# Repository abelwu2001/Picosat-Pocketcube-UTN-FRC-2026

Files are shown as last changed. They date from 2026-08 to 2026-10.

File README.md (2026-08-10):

# PocketQube PoCat: análisis, ensayos y propuestas de mejora

Este repositorio reúne la documentación, los diseños electrónicos y los resultados del estudio del satélite **PocketQube PoCat**. El trabajo parte de un diseño existente y busca identificar mejoras comprobables mediante simulaciones, mediciones y comparaciones con la versión original.

> [!IMPORTANT]
> Antes de modificar una placa, hay que confirmar su revisión, función, compatibilidad mecánica y relación con las demás placas del satélite. Todos los cambios deben realizarse sobre una copia del diseño original.

## Objetivos del proyecto

- Comprender el funcionamiento completo del PocketQube.
- Identificar la función y las conexiones de cada placa.
- Reunir los resultados obtenidos por los desarrolladores del diseño original.
- Detectar limitaciones reales mediante mediciones o simulaciones.
- Seleccionar una mejora técnicamente justificable.
- Comparar el comportamiento del diseño original con el modificado.
- Documentar el procedimiento y los resultados para que puedan reproducirse.

## Configuración del satélite

### Placas y elementos principales

| Carpeta o placa | Función principal | Uso en la configuración |
|---|---|---|
| `pq_obc_comms` | Computadora de a bordo y comunicación LoRa | Se utiliza |
| `pq_eps` | Gestión de energía, MPPT, batería y distribución de tensiones | Se utiliza |
| `pq_adcs` | Determinación y control de actitud | A seleccionar (hay dos para eligir) |
| `pq_ymag_board` | Magnetorquer del eje Y | Se utiliza |
| `pq_latboard` | Placas laterales con panel solar y sensores; una incorpora la antena | Se utilizan varias unidades |
| `pq_botboard` | Placa inferior, panel solar, batería, umbilical y *killswitches* | Se utiliza |
| `pq_botnotsobot` | Placa inferior deslizante o estructural del conjunto | Se utiliza |
| `pq_pl1` | Payload de cámara VGA | A seleccionar |
| `pq_pl2` | Payload de detección RFI en banda L | A seleccionar |
| `pq_topboard` | Placa superior genérica | Alternativa al payload, según la configuración |
| `pq_egse` | Equipo eléctrico de apoyo y pruebas en tierra | No vuela |
| `assembly` | Modelos y archivos del ensamblaje mecánico | Solo documentación/diseño |

> [!WARNING]
> Puede cambiar.

## Orden funcional del sistema

El recorrido general de energía, control y datos puede resumirse así:

1. Los paneles solares entregan energía a la `pq_eps`.
2. La EPS administra la carga de la batería y alimenta las demás placas.
3. La `pq_obc_comms` controla el satélite y transmite o recibe información.
4. La `pq_adcs` mide y controla la orientación mediante sensores y magnetorquers.
5. La `pq_pl2` realiza las mediciones de interferencia en banda L.

## Posibles líneas de mejora

### 1. Mejorar el sistema de energía

- Aumentar la eficiencia de los convertidores.
- Revisar el funcionamiento del MPPT.
- Reducir el rizado de las alimentaciones.
- Mejorar el diseño térmico y las pistas de potencia.
- Disminuir las emisiones de las etapas conmutadas.

### 2. Mejorar el sistema de comunicaciones

- Optimizar la adaptación de la antena a `50 Ω`.
- Revisar la pista RF y su camino de retorno.
- Reducir armónicos del transmisor.
- Mejorar el mecanismo de despliegue.
- Comparar alcance, potencia y sensibilidad.

### 3. Mejorar el control de actitud

- Calibrar magnetómetro, giróscopo y sensores solares.
- Filtrar ruido y deriva de los sensores.
- Mejorar el algoritmo de estimación y control.
- Optimizar el accionamiento de los magnetorquers.
- Evitar que las bobinas interfieran con el magnetómetro.

### 4. Reducir interferencias electromagnéticas

- Medir el piso de ruido de PL2 en forma aislada.
- Encender cada subsistema por separado para identificar la fuente de ruido.
- Revisar planos de masa y caminos de retorno.
- Agregar filtros, ferritas, desacoplos o blindaje cuando corresponda.
- Evaluar una ventana silenciosa de medición mediante firmware.
- Comparar los espectros antes y después de la modificación.

### 5. Mejorar el payload de cámara

- Aumentar resolución o calidad de imagen.
- Reducir el consumo entre capturas.
- Incorporar memoria o compresión.
- Mejorar el protocolo de transferencia.

## Links de trabajo 

> [!NOTE]
> **Links**
>
> ```text
> Note one:
> Trello: 
> Drive:
> ```

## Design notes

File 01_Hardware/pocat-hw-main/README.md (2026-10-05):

# IEEE Open PocketQube Kit – Hardware necesario

Este documento resume las placas, elementos estructurales,
componentes externos, cableado y tornillería necesarios para
el armado de la plataforma PocketQube.

> Nota:
> No se incluyen aquí payloads específicos de las variantes
> demostradoras de la Wiki. La carga útil se considera un
> subsistema independiente/custom.
>
> Las cantidades se basan principalmente en la documentación
> de montaje y hardware del IEEE Open PocketQube Kit.
> Algunas revisiones del repositorio y de la Wiki presentan
> pequeñas diferencias, por lo que siempre debe comprobarse
> la revisión final de PCB antes de comprar componentes.

Link de la wiki donde se explica todo sobre el proyecto:
 
>https://wiki.nanosatlab.space/shelves/ieee-open-pocketqube-kit-mFR

Link BOM final

>https://docs.google.com/spreadsheets/d/18evn2hEh3wvYzuJMzKZhzkFULgpysAK2np7i2tM_1j0/edit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

# 1. PLACAS PCB

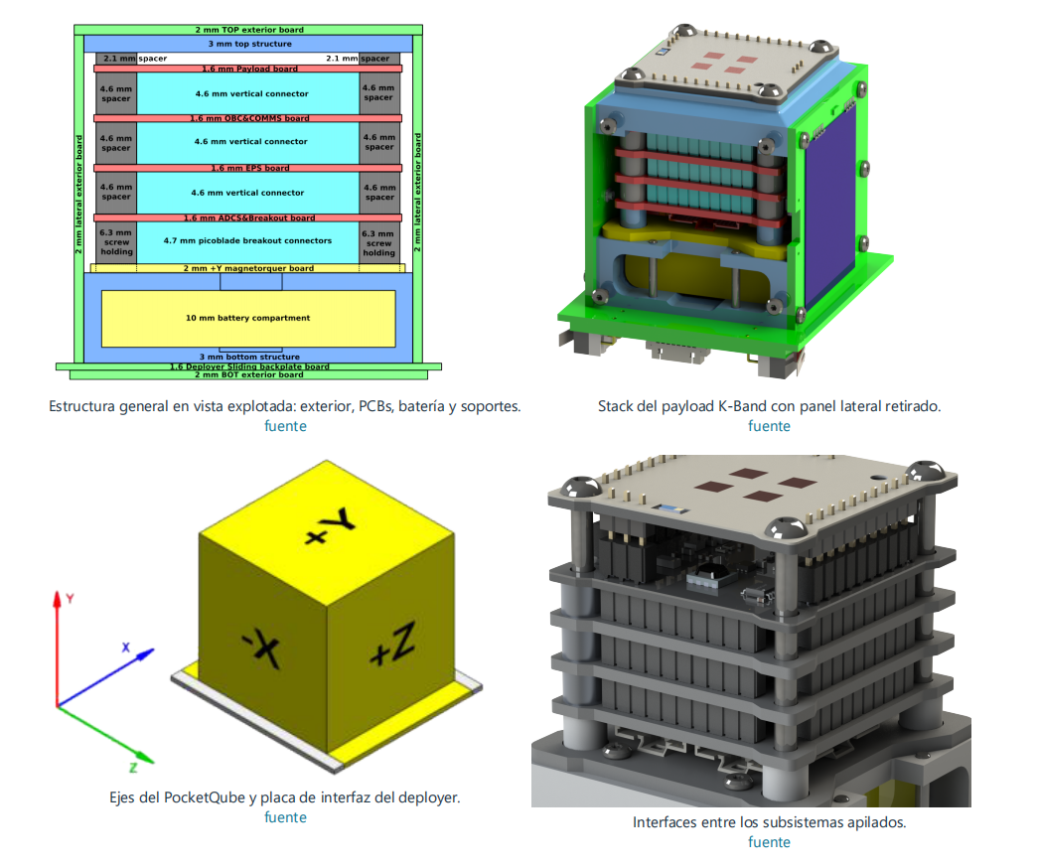
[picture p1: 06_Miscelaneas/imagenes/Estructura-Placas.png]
Estructura de Placas


## 1.1 Placas del PocketQube

| **Cantidad** | **Placa** | **Función** |
|---:|---|---|
| 1 | **PQ_ADCS_HBridge** | Control de actitud: recibe sensores y maneja los magnetorquers mediante puentes H. |
| 1 | **PQ_EPS** | Sistema de potencia: recibe energía solar, carga la batería y distribuye las tensiones del satélite. |
| 1 | **pq_obc_comms** | Computadora principal + comunicaciones por radio con tierra. |
| 1 | **pq_topboard** | Cara superior estructural e interfaz de la zona del payload. |
| 1 | **pq_botboard** | Cara inferior; integra celda solar, sensores y un magnetorquer eje -Y PCB. |
| 4 | **pq_latboard** | Caras laterales +X, -X, +Z y -Z. Integran celda solar, sensores y magnetorquer; una lleva además la antena COMMS. |
| 1 | **PQ_MagYBoard** | Magnetorquer interno dedicado al eje +Y. |
| 1 | **pq_botnotsobot** | Placa mecánica asociada al sliding/deployer y al sistema de despliegue. |
| **11** | **Total PCBs del conjunto** | Sin contar payload custom ni EGSE. |

### Magnetorquers

El PocketQube utiliza **6 magnetorquers**:

- 4 integrados en las `pq_latboard`
- 1 integrado en la `pq_botboard`
- 1 en la `PQ_MagYBoard`

Los magnetorquers integrados en las placas se forman mediante
pistas/bobinas de cobre del propio PCB, por lo que no se compran
como componentes independientes.

## 1.2 Placa de soporte en tierra

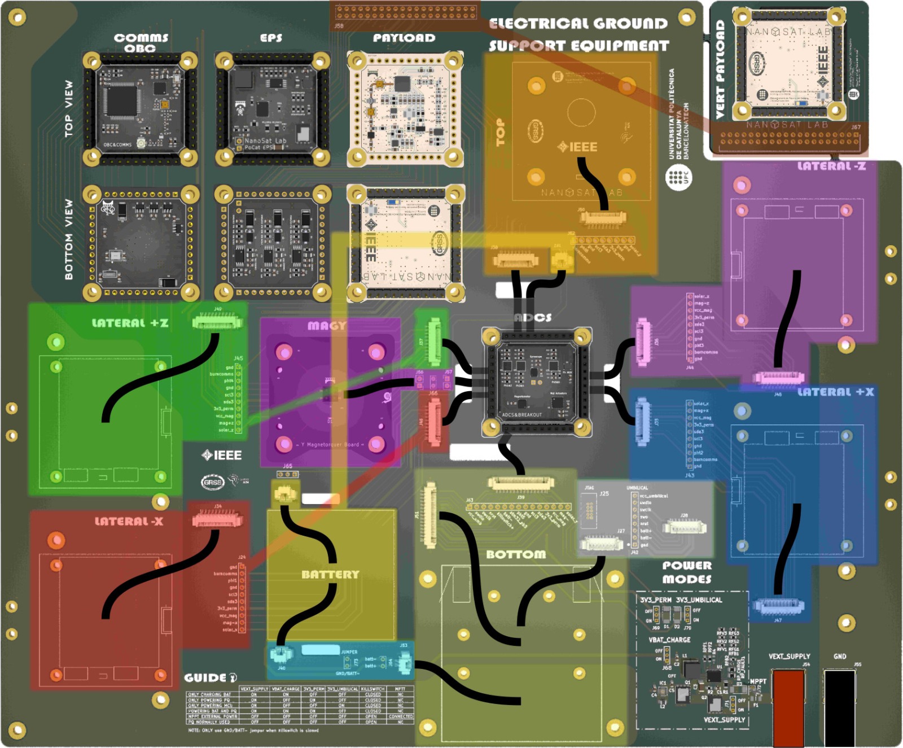
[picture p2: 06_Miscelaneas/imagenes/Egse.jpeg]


## Cableado e interconexiones

| ID | From | Num. of cables | Connector | To | Num. of cables | Connector | Length (mm) |
|---:|---|---:|---|---|---:|---|---:|
| 1 | Lat +Z | 10 | PicoBlade | PCB Connector | 10 | PicoBlade | |
| 2 | PCB Connector | 10 | PicoBlade | ADCS | 10 | PicoClasp | |
| 3 | Lat -Z | 10 | PicoBlade | PCB Connector | 10 | PicoBlade | |
| 4 | PCB Connector | 10 | PicoBlade | ADCS | 10 | PicoClasp | |
| 5 | Lat +X | 10 | PicoBlade | PCB Connector | 10 | PicoBlade | |
| 6 | PCB Connector | 10 | PicoBlade | ADCS | 10 | PicoClasp | |
| 7 | Lat -X | 10 | PicoBlade | PCB Connector | 10 | PicoBlade | |
| 8 | PCB Connector | 10 | PicoBlade | ADCS | 10 | PicoClasp | |
| 9 | Battery | 2 | PicoBlade | - | - | - | |
| 10 | PCB Connector | 2 | PicoBlade | Bottom Board | 2 | PicoBlade | |
| 11 | Battery Heater & NTC | 3 | PicoClasp | - | - | - | |
| 12 | PCB Connector | 3 | PicoClasp | ADCS | 3 | PicoClasp | |
| 13 | Umbilical | 8 | PicoBlade | PCB Connector | 8 | PicoBlade | |
| 14 | Bottom Board | 15 | PicoBlade | PCB Connector | 15 | PicoBlade | |
| 15 | PCB Connector | 15 | PicoBlade | ADCS | 15 | PicoClasp | |
| 16 | Top Board | 9 | PicoBlade | PCB Connector | 9 | PicoBlade | |
| 17 | PCB Connector | 9 | PicoBlade | ADCS | 9 | PicoClasp | |

La EGSE no forma parte del hardware de vuelo. Se utiliza en banco
para alimentación, mediciones, depuración e integración.

Por lo tanto:

- PCBs del PocketQube: 11
- PCB EGSE: 1
- Total a fabricar si se realiza todo el conjunto: 12

# 2. BATERÍA

| Cantidad | Elemento | Especificación |
|---:|---|---|
| 1 | Batería Li-ion | 3.7 V |
| 1 | Capacidad nominal | 1400 mAh |
| 1 | Energía nominal | 5.18 Wh |
| 1 | Modelo indicado en Assembly Wiki | 103540 |

La batería se instala dentro de la estructura inferior.

IMPORTANTE:
La documentación del proyecto posee revisiones que mencionan
otras baterías. Para este listado se conserva la especificación
indicada en la página de Assembly de la Wiki.

# 3. CELDAS SOLARES

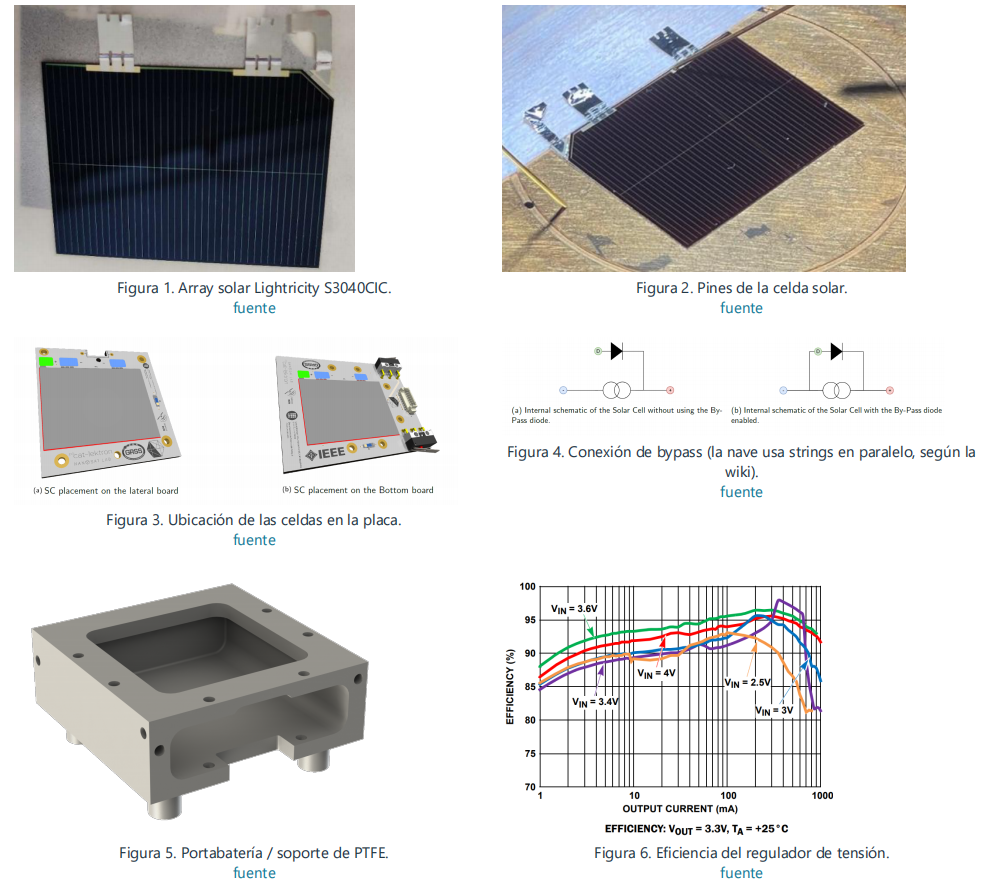
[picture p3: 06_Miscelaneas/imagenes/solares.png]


Modelo indicado:

Lightricity S3040_CIC

Características aproximadas indicadas en la Wiki:

- Tecnología: Triple Junction GaAs
- Integración: CIC
- Dimensiones: 40.15 x 30.35 x 0.30 mm
- Área fotovoltaica activa: 12 cm²
- Tensión AM0: ~2.5 V
- Potencia AM0: ~0.5 W

## Cantidad

| Ubicación | Cantidad |
|---|---:|
| Lateral +X | 1 |
| Lateral -X | 1 |
| Lateral +Z | 1 |
| Lateral -Z | 1 |
| Bottom board | 1 |
| **TOTAL** | **5** |

La plataforma utiliza:

**5 x Lightricity S3040_CIC**

La cara superior/payload no lleva celda solar en esta
configuración de la Wiki.

# 4. FOTODIODOS

Modelo indicado:

**SLCD-61N8 – Advanced Photonix**

La arquitectura ADCS utiliza un fotodiodo en cada cara para
determinar la incidencia de radiación solar.

| Ubicación | Cantidad |
|---|---:|
| Cuatro lateral boards | 4 |
| Top board | 1 |
| Bottom board | 1 |
| **TOTAL** | **6** |

Cantidad a comprar:

**6 x SLCD-61N8**

Datos principales indicados en la documentación:

- Isc aproximada: 170 µA
- Voc aproximada: 0.4 V
- Máxima sensibilidad: 930 nm
- Acceptance Half Angle: 60°

# 5. SENSORES DE TEMPERATURA

Modelo:

**TCN75A / TCN75AVOA – Microchip**

La Wiki especifica un sensor de temperatura en cada placa
lateral.

Cantidad mínima documentada para las caras laterales:

**4 x TCN75A**

Características:

- Interfaz: I2C
- Rango: -40 °C a +125 °C
- Precisión: aproximadamente ±1 °C
- Bajo consumo

Verificar en la BOM final de `topboard` y `botboard` si la
revisión fabricada incorpora sensores de temperatura
adicionales.

# 6. KILLSWITCHES

El PocketQube utiliza:

**2 x killswitches**

Los dos interruptores están conectados en serie para proporcionar
redundancia.

Su función es mantener desconectada la batería mientras el
PocketQube se encuentra dentro del deployer.

Cuando el PocketQube es liberado:

1. los killswitches dejan de estar presionados;
2. se habilita la alimentación;
3. comienza la secuencia de encendido.

IMPORTANTE:
La Wiki de Assembly los describe asociados a la estructura/PCB
inferior. El repositorio también contiene `pq_botnotsobot`,
relacionado con la interfaz de despliegue. Confirmar la ubicación
mecánica exacta con la revisión final que se vaya a fabricar.

# 7. SISTEMA DE ANTENA COMMS

Se necesita una placa lateral configurada para comunicaciones.

Elementos principales:

| Cantidad | Elemento |
|---:|---|
| 1 | Antena desplegable de cinta metálica |
| 1 | Cable RF desde OBC-COMMS |
| 1 | Dyneema / UHMWPE |
| 1 | Resorte de extensión |
| 1 | Jumper SMT de guiado |
| 2 | Resistencias thermal-knife |
| 1 | Cable clip / sujeción de antena |
| 2 | Tornillos M2.5 asociados al mecanismo |
| según diseño | Inserts/elementos de fijación |

## Dyneema

Especificación indicada:

- UHMWPE
- diámetro: 0.35 mm
- resistencia aproximada: 26 kg

La documentación de mantenimiento utiliza aproximadamente
40 cm para realizar el montaje, dejando excedente para los
nudos.

## Resorte

Modelo indicado:

**McMaster-Carr 5108N98**

Su función es mantener tensión constante sobre el Dyneema.

## Jumper SMT

Modelo indicado:

**Harwin S1731-46R**

Se utiliza como guía y para mantener el Dyneema en contacto con
los thermal knives.

## Thermal knives

La revisión actual de la página del deployer utiliza:

**2 x resistencias de baja impedancia**

Valor actualmente indicado:

**4.7 ohm**

Estas resistencias son calentadas eléctricamente mediante
`BURNCOMMS`, cortando/fundiendo el Dyneema y permitiendo que la
antena se despliegue.

IMPORTANTE:
Documentación anterior de mantenimiento menciona 7.5 ohm.
Comprobar siempre el esquemático de la revisión fabricada antes
de comprar las resistencias.

# 8. CABLEADO INTERNO

## Laterales ↔ ADCS

Cantidad:

**4 x cables planos de 10 vías PicoClasp ↔ PicoBlade**

Uno para cada lateral:

- +X
- -X
- +Z
- -Z

Cada lateral debe conectarse al conector correspondiente del
ADCS para conservar correctamente la orientación de los ejes.

## Bottom structure ↔ ADCS

Cantidad:

**1 x cable plano de 15 vías**

Conecta la estructura/PCBs inferiores con el ADCS.

## Batería

Cantidad:

**1 x cable/conector PicoBlade para batería**

La batería se conecta desde la estructura inferior.

## NTC + heater de batería

Previsto:

**1 x cable plano de 3 vías**

Conecta:

- NTC de batería
- Battery heater
- ADCS

NOTA:
La propia Wiki indica que este sistema todavía no estaba
implementado en la versión del assembly documentada.

Debe considerarse:

**OPCIONAL / A VERIFICAR SEGÚN REVISIÓN**

## Cable RF

Cantidad:

**1 x cable RF/coaxial**

Ruta:

OBC-COMMS
↓
Lateral Board COMMS
↓
Antena

# 9. CONECTOR UMBILICAL

La Bottom Board incluye una interfaz umbilical.

Se utiliza para:

- carga de batería;
- alimentación externa;
- debugging;
- NRST;
- SWCLK;
- SWDIO;
- tensión de referencia/alimentación.

Debe contemplarse:

- conector umbilical en PCB;
- conector complementario;
- cable correspondiente para banco/EGSE.

# 10. ESTRUCTURA MECÁNICA

## Estructuras principales

| Cantidad | Elemento |
|---:|---|
| 1 | Top Structure |
| 1 | Bottom Structure |
| 1 | Sliding Plate |

### Top Structure

Espesor indicado en Assembly:

**3 mm**

### Bottom Structure

La Wiki la describe mediante una configuración estructural de:

**3 mm + 10 mm + 3 mm**

### Sliding Plate

Dimensiones de referencia del estándar 1P:

- ancho: 58.0 ± 0.1 mm
- largo: 64.0 ± 0.1 mm
- espesor de referencia: 1.6 mm

# 11. TORNILLERÍA

## Tornillos

| Cantidad | Tipo |
|---:|---|
| 4 | M2 x 6 ISO 14580 |
| 2 | M2 x 20 ISO 14580 |
| 20 | M2 x 5 ISO 14850 |

## Tornillos principales del stack

Se requieren además:

**4 x tornillos/standoffs M3**

La longitud debe definirse según la altura final del stack y
de la carga útil custom.

NO se fija aquí M3x30 o M3x35 porque esos valores corresponden
a configuraciones concretas de payload documentadas en la Wiki.

# 12. SPACERS

| Cantidad | Elemento |
|---:|---|
| 4 | M2 x 5 mm Nylon |
| 4 | M3 x 2 mm Aluminium |
| 12 | M3 x 4 mm Aluminium |
| 12 | M3 x 0.5 mm Aluminium |
| según necesidad | M3 x 0.1–0.5 mm Aluminium |

La Wiki indica agregar los spacers finos necesarios para obtener
aproximadamente:

**4.6 mm de separación entre PCBs**

# 13. HELICOILS / INSERTOS ROSCADOS

| Cantidad | Tipo |
|---:|---|
| 4 | HELICOIL PLUS FREE RUNNING M3 x 2D INOX |
| 16 | HELICOIL PLUS FREE RUNNING M2 x 1.5D INOX |
| 10 | HELICOIL PLUS FREE RUNNING M2 x 1D INOX |

Uso general:

- M3: tornillos principales/standoffs;
- M2 x 1.5D: fijación de laterales;
- M2 x 1D: Bottom Board / Bottom Structure.

# 14. ARANDELAS

Cantidad:

**12 x arandelas 3.2 x 6 x 0.5 mm INOX A2 DIN 433**

También cumplen función de ajuste fino de separación mecánica.

# 15. MAGNETORQUERS

La plataforma utiliza magnetorquers PCB.

No es necesario comprar bobinas externas para los siguientes:

- +X
- -X
- +Z
- -Z
- -Y

Estos están integrados en las placas exteriores mediante pistas
de cobre.

Para el eje restante se utiliza:

**1 x PQ_MagYBoard**

correspondiente al magnetorquer interno del eje +Y.

# 16. ELEMENTOS DE LA BATERÍA

Además de la batería se contempla:

| Cantidad | Elemento | Estado |
|---:|---|---|
| 1 | NTC de batería | previsto |
| 1 | Battery heater | previsto |
| 1 | Cable 3 vías | previsto |

La Wiki indica que el NTC/heater estaba previsto pero no
implementado todavía en el assembly documentado.

Por lo tanto debe verificarse antes de realizar la compra.

# 17. CONSUMIBLES DE MONTAJE

Conviene disponer de:

- Kapton tape
- Aluminum tape
- Soldadura
- Flux
- Material de limpieza de PCB
- Elementos de crimpado
- Terminales PicoBlade
- Terminales PicoClasp
- Cableado de repuesto
- Tornillos y spacers adicionales

# 18. TORQUES DE REFERENCIA

La Wiki proporciona como referencia:

| Tornillo | Torque |
|---|---:|
| M2 | 0.2 Nm |
| M2.5 | 0.5 Nm |
| M3 | 1 Nm |
| M4 | 2 Nm |

Para la tornillería específica del PocketQube deben respetarse
los valores y límites definidos para la estructura final.

# 19. RESUMEN DE ELEMENTOS PRINCIPALES A COMPRAR

## Hardware externo principal

| Cantidad | Elemento |
|---:|---|
| 1 | Batería Li-ion 3.7 V / 1400 mAh |
| 5 | Celdas solares Lightricity S3040_CIC |
| 6 | Fotodiodos SLCD-61N8 |
| 4 mínimo | Sensores TCN75A |
| 2 | Killswitches |
| 1 | Antena COMMS |
| 1 | Cable RF |
| 1 | Dyneema 0.35 mm |
| 1 | Resorte McMaster-Carr 5108N98 |
| 1 | Harwin S1731-46R |
| 2 | Resistencias thermal-knife |
| 4 | Cables 10 vías PicoClasp-PicoBlade |
| 1 | Cable 15 vías |
| 1 | Cable/conector de batería |
| 1 | Cable 3 vías NTC/heater (si se implementa) |
| 1 | Conjunto de conector umbilical |

# 20. RESUMEN GENERAL

Para construir la plataforma completa se debe contemplar:

### Fabricación PCB

- 11 PCBs correspondientes al PocketQube.
- 1 PCB EGSE para soporte en tierra.
- Payload custom tratado independientemente.

### Energía

- 1 batería.
- 5 celdas solares.
- Cableado de batería.
- Interfaz umbilical.

### ADCS

- 6 fotodiodos.
- 4 sensores de temperatura laterales como mínimo.
- Magnetorquers integrados en las PCBs.
- 1 Magnetorquer PCB +Y.

### Seguridad / despliegue

- 2 killswitches.
- Antena desplegable.
- Dyneema.
- 2 thermal knives.
- Resorte.
- Jumper SMT.
- Sistema mecánico de sujeción.

### Interconexión

- 4 cables laterales de 10 vías.
- 1 cable inferior de 15 vías.
- 1 cable de batería.
- 1 cable RF.
- 1 cable NTC/heater si se implementa.

### Mecánica

- Top Structure.
- Bottom Structure.
- Sliding Plate.
- Tornillería M2/M3.
- Spacers.
- Helicoils.
- Arandelas.
- Kapton y materiales auxiliares.

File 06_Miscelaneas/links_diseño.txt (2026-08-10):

Diseño PCB
-----------
https://github.com/orgs/nanosatlab/repositories?utm_source=chatgpt.com

PAE Quadrimestre Tardor (QT) 2025 - On-Board Computer Software (OBC-sw) 

IEEE PocketQubes 

pocat-lektron-sw: Software developed by the IEEE GRSS Open PocketQube kit developed at the UPC NanoSat Lab. The software is also used by the PoCat-Lektron mission that is composed by PoCat-2 and PoCat-3. 

pocat-lektron-arduinoGS

tinyGS-antenna

reflow-oven

------------------------------------------------------------------------------

Software
--------

https://github.com/nanosatlab/pocat-lektron-sw?utm_source=chatgpt.com

------------------------------------------------------------------------------

Usan el STM32L476RGTX

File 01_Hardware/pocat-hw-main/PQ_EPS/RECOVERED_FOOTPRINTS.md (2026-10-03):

# Huellas recuperadas del PCB

Recovered_Project.pretty contiene una copia editable por instancia de las huellas embebidas en este PCB, exportada con KiCad. Los nombres incluyen referencia y UUID abreviado para conservar variantes y modificaciones locales. recovered-footprints.json registra el identificador original, el nuevo y los hashes.

Esta biblioteca es una instantánea del diseño existente; no representa validación del fabricante ni del repositorio NSL. Conserva también cualquier defecto pendiente de pads, courtyards o geometría. Las reglas DRC permanecen activas y los cambios futuros respecto de esta instantánea vuelven a producir avisos de discrepancia.

La operación cambia únicamente los identificadores de biblioteca del PCB y la propiedad Footprint de los símbolos colocados correspondientes. Se verifica que la serialización nativa del PCB sea idéntica salvo esos identificadores; no se sustituyen pads ni se modifican redes. Los modelos 3D conservan sus rutas originales y pueden requerir dependencias externas.

Para comparar con la fuente histórica, consultar original_fpid y sources/nanosatlab. No ejecutar Actualizar huellas desde bibliotecas de forma masiva con las bibliotecas actuales ajenas a esta instantánea sin revisar diferencias.

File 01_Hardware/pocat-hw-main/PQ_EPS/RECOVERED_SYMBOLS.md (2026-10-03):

# Símbolos recuperados del esquemático

Recovered_Symbols contiene las definiciones embebidas del proyecto. sym-lib-table conserva sus nicknames originales y apunta a estas copias locales. El esquemático y sus lib_id, pines, tipos eléctricos, cables, redes y reglas ERC permanecen intactos.

Son instantáneas del diseño histórico, no bibliotecas validadas por el fabricante. Los defectos y las variantes locales se conservan. recovered-symbols.json registra los bloques de origen mediante hashes y cualquier traducción estructural de nombre. Embedded_Local_Variants conserva exactamente los símbolos locales lib_name; si falta una definición canónica, se deriva de una de esas variantes renombrando únicamente los nombres estructurales de símbolo.

No se añadieron PWR_FLAG, exclusiones ni cambios de severidad para eliminar errores eléctricos. Los avisos de diferencia reales entre variantes locales y su definición canónica deben revisarse expresamente.

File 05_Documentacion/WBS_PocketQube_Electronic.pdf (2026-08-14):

## UNIVERSIDAD TECNOLÓGICA NACIONAL

## Facultad Regional Córdoba

# PocketQube UTN-FRC 2026

# Estructura de Desglose del Trabajo

# Work Breakdown Structure (WBS)

## Baseline: Payload PL2 - Radiómetro de banda L

Código: | PKQ-WBS-001
Revisión: | A
Estado: | Propuesta
Fecha: | 12 de agosto de 2026

PocketQube UTN-FRC 2026 | PKQ-WBS-001 | Rev. A

## Control del documento

Código | PKQ-WBS-001 | Revisión | A
Título | WBS general del proyecto PocketQube | Estado | Propuesta
Configuración | PocketQube con payload PL2 de banda
| L
Propósito | Definir el 100% del trabajo necesario
| para revisar, integrar, verificar y mejo-
| rar el diseño, con especial profundidad
| en EMC y PL2.

## Criterio de uso

Esta WBS está orientada a entregables. Las filas de nivel 3 son paquetes de trabajo controlables: cada una posee responsable, dependencia, entregable y criterio de cierre. Las fechas y los nombres personales deben completarse en la planilla editable una vez aprobados el cronograma y la matriz RACI.

- La configuración base incorpora PL2. PL1 y la topboard no se suman simultáneamente a la baseline de vuelo.
- La baseline física considera 11 placas; el EGSE integral es equipo de laboratorio, permite estimular, medir y probar el PocketQube completo en tierra, y no vuela.
- El cierre de un paquete requiere evidencia verificable, no solamente la ejecución de la actividad.
- Los cambios de alcance deben registrarse en configuración y reflejarse en requisitos, WBS y matriz V&V.

## Vista jerárquica de nivel 1

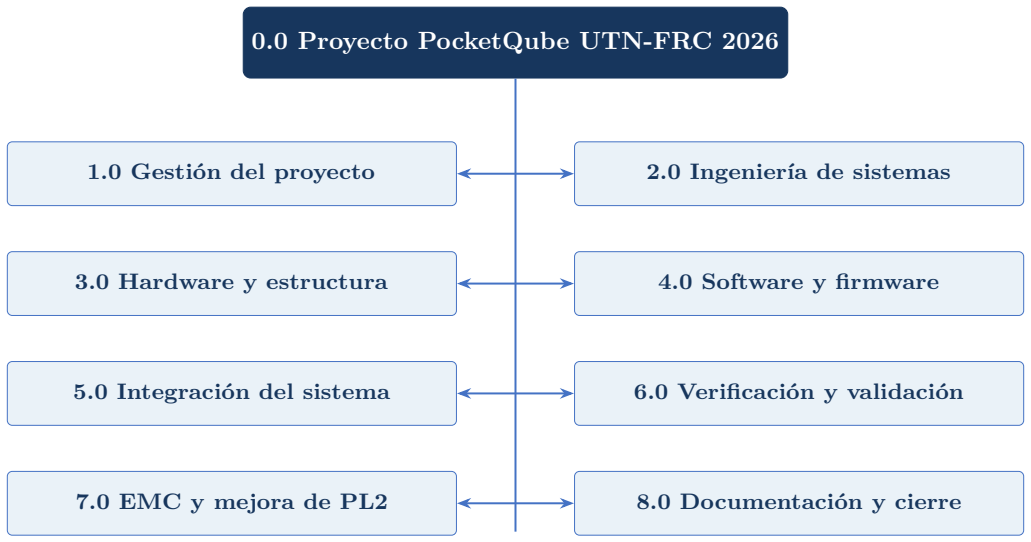
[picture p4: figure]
0.0 Proyecto PocketQube UTN-FRC 2026; 1.0 Gestión del proyecto; 2.0 Ingeniería de sistemas; 3.0 Hardware y estructura; 4.0 Software y firmware; 5.0 Integración del sistema; 6.0 Verificación y validación

7.0 EMC y mejora de PL2 | 8.0 Documentación y cierre

PocketQube UTN-FRC 2026 | PKQ-WBS-001 | Rev. A

## Resumen de fases

WBS

Fase | Propósito | Responsable funcional

1.0

Gestión del proyecto | Organizar alcance, recursos, configuración, riesgos y seguimiento del proyecto. | Líder de proyecto

2.0

Ingeniería de sistemas Convertir la necesidad de misión en requisitos, arquitectura, interfaces y presupuestos verificables.
Ingeniería de
sistemas

3.0

Hardware y estructura Revisar, caracterizar, fabricar e integrar el hardware de vuelo y sus elementos estructurales.

Equipo de hardware

4.0

Software y firmware Desarrollar el software embebido, protocolos, modos operativos y soporte de prueba.

Firmware

5.0

Integración del sistema Poner en marcha cada placa, integrar el stack y establecer una baseline funcional medible.

Ingeniería de
sistemas

6.0

Verificación y validación | Demostrar mediante evidencia objetiva que el sistema cumple sus requisitos y criterios de aceptación.

Ensayos/EMC

7.0

EMC y mejora de PL2 Identificar interferencias internas sobre el radiómetro PL2, aplicar una mejora y demostrar el cambio antes/después.

Ensayos/EMC

8.0

Documentación y
cierre

Consolidar revisiones, evidencias, entregables académicos y lecciones aprendidas.

Documentación

## Índice

1 1.0 Gestión del proyecto | 4
2 2.0 Ingeniería de sistemas | 5
3 3.0 Hardware y estructura | 6
4 4.0 Software y firmware | 8
5 5.0 Integración del sistema | 9
6 6.0 Verificación y validación | 11
7 7.0 EMC y mejora de PL2 | 13
8 8.0 Documentación y cierre | 14
Criterios para aprobar la línea base WBS | 15

PocketQube UTN-FRC 2026 PKQ-WBS-001 | Rev. A 1 1.0 Gestión del proyecto Organizar alcance, recursos, configuración, riesgos y seguimiento del proyecto. Responsable funcional de fase: Líder de proyecto WBS Paquete / actividad Entregable Responsable Dep. Criterio de cierre OK 1.1 Iniciación y organización 1.1.1 Definir alcance, misión y objetivo de mejora Acta de alcance Líder de proyecto — Alcance y exclusiones aprobados por el equipo □ 1.1.2 Identificar interesados y contactos técnicos Registro de interesados Líder de proyecto 1.1.1 Interesados, necesidades y canales de consulta registrados □ 1.1.3 Asignar roles y responsabilidades Matriz RACI Equipo completo 1.1.1 Cada paquete de trabajo tiene un responsable y un aprobador □ 1.2 Planificación 1.2.1 Definir cronograma, hitos y revisiones Cronograma maestro Líder de proyecto 1.1.3 Hitos PDR, CDR, TRR y cierre ubicados en el calendario □ 1.2.2 Estimar recursos, costos y proveedores Presupuesto y lista de proveedores Líder de proyecto 1.1.1 Costos y recursos críticos estimados con fuente □ 1.2.3 Planificar compras y disponibilidad de laboratorio Plan de adquisiciones Líder de proyecto 1.2.2 Ítems de largo plazo e instalaciones reservadas □ 1.3 Configuración y documentación 1.3.1 Definir DMS y estructura del repositorio Plan de gestión documental Documentación 1.1.1 Carpetas, códigos y responsables documentales definidos □ 1.3.2 Controlar versiones y líneas base Registro de versiones y baselines Documentación 1.3.1 Cada entregable liberado tiene código, revisión y estado □ 1.3.3 Gestionar cambios y decisiones técnicas Change log y decision log Ingeniería de sistemas 1.3.2 Cambios trazados con motivo, impacto y aprobación □ 1.4 Riesgos y seguimiento 1.4.1 Identificar y actualizar riesgos Matriz de riesgos Ingeniería de sistemas 1.1.1 Riesgos priorizados con mitigación, dueño y fecha de revisión □ 1.4.2 Realizar reuniones técnicas y minutas Minutas de reunión Líder de proyecto 1.1.3 Decisiones, acciones, responsables y vencimientos registrados □ 1.4.3 Emitir estado periódico del WBS Informe de avance Líder de proyecto 1.2.1 Avance, bloqueos y próximos hitos actualizados □

Página 4 de 15

PocketQube UTN-FRC 2026 PKQ-WBS-001 | Rev. A 2 2.0 Ingeniería de sistemas Convertir la necesidad de misión en requisitos, arquitectura, interfaces y presupuestos verificables. Responsable funcional de fase: Ingeniería de sistemas WBS Paquete / actividad Entregable Responsable Dep. Criterio de cierre OK 2.1 Requisitos y trazabilidad 2.1.1 Definir necesidad de misión y concepto de operación CONOPS Ingeniería de sistemas 1.1.1 Escenarios, actores, modos y productos de misión aprobados □ 2.1.2 Consolidar requisitos de sistema Especificación de requisitos Ingeniería de sistemas 2.1.1 Requisitos únicos, medibles y con fuente identificada □ 2.1.3 Asignar requisitos a subsistemas Árbol de requisitos Ingeniería de sistemas 2.1.2 Todo requisito de sistema está asignado a uno o más subsistemas □ 2.1.4 Construir matriz de trazabilidad y V&V RTM y matriz V&V Ingeniería de sistemas 2.1.3 Cada requisito tiene método, evidencia y criterio de verificación □ 2.2 Arquitectura y configuración 2.2.1 Definir arquitectura funcional Diagrama funcional Ingeniería de sistemas 2.1.2 Funciones, flujos de energía, datos y control identificados □ 2.2.2 Definir configuración física de vuelo con PL2 Árbol de producto y configuración Ingeniería de sistemas 2.2.1 Configuración de 11 placas físicas documentada; PL1 y topboard excluidos de la baseline □ 2.2.3 Definir interfaces eléctricas, mecánicas y de datos ICD de sistema Ingeniería de sistemas 2.2.2 Conectores, señales, tensiones, protocolos y tolerancias definidos □ 2.2.4 Definir modos operativos y transiciones Máquina de estados del sistema Firmware 2.1.1 Modos seguros, nominales, payload y contingencia definidos □ 2.3 Presupuestos de ingeniería 2.3.1 Elaborar presupuesto de masa y centro de gravedad Mass budget Mecánica 2.2.2 Masa, margen y centro de gravedad estimados por elemento □ 2.3.2 Elaborar presupuesto de potencia y energía Power budget Electrónica de potencia 2.2.4 Consumo y balance energético cerrados por modo con margen □ 2.3.3 Elaborar presupuesto de datos y memoria Data budget Firmware 2.2.4 Tasas, volúmenes, almacenamiento y tiempos de descarga estimados □ 2.3.4 Elaborar presupuesto de enlace Link budget RF/Comunicaciones 2.2.1 Margen de enlace calculado para escenarios nominal y desfavorable □ 2.3.5 Asignar márgenes térmicos y EMC Presupuesto térmico y EMC Ensayos/EMC 2.2.3 Límites de temperatura y compatibilidad asignados a subsistemas □

Página 5 de 15

PocketQube UTN-FRC 2026 PKQ-WBS-001 | Rev. A 3 3.0 Hardware y estructura Revisar, caracterizar, fabricar e integrar el hardware de vuelo y sus elementos estructurales. Responsable funcional de fase: Equipo de hardware WBS Paquete / actividad Entregable Responsable Dep. Criterio de cierre OK 3.1 EPS y sistema de energía 3.1.1 Revisar esquemático, PCB y BOM de la EPS Informe de revisión EPS Electrónica de potencia 2.2.3 Hallazgos clasificados y revisión de placa identificada □ 3.1.2 Verificar MPPT, batería y caminos de potencia Modelo funcional de energía Electrónica de potencia 3.1.1 Protecciones, límites y secuencias de energía verificados □ 3.1.3 Caracterizar eficiencia, ripple y temperatura Informe de caracterización EPS Electrónica de potencia 5.2.1 Curvas de eficiencia y ruido obtenidas para cargas representativas □ 3.2 OBC y comunicaciones 3.2.1 Revisar STM32, memoria e interfaces del OBC Informe de revisión OBC RF/Comunicaciones 2.2.3 Interfaces y recursos del OBC trazados contra requisitos □ 3.2.2 Revisar cadena RF del SX1262 y adaptación Informe RF y red de adaptación RF/Comunicaciones 3.2.1 Trayecto de 50 ohm, matching y pérdidas documentados □ 3.2.3 Caracterizar antena, despliegue y emisiones Informe de comunicaciones RF/Comunicaciones 5.2.2 Potencia, sensibilidad, S11, armónicos y despliegue medidos □ 3.3 ADCS y magnetorquers 3.3.1 Revisar sensores, drivers y alimentación del ADCS Informe de revisión ADCS ADCS 2.2.3 Sensores y actuadores asociados a interfaces y requisitos □ 3.3.2 Caracterizar Y-MAG y accionamiento magnético Informe de magnetorquer ADCS 5.2.3 Momento magnético, corriente, potencia y temperatura medidos □ 3.3.3 Calibrar sensores y validar control de detumbling Modelo y resultados ADCS ADCS 4.3.3 Offsets, escalas y reducción de velocidad angular cuantificados □ 3.4 Payload PL2 de banda L 3.4.1 Revisar arquitectura RF y banda de operación de PL2 Informe de revisión PL2 Ensayos/EMC 2.2.3 Cadena de 1 a 2 GHz, puntos de prueba y revisión de placa documentados □ 3.4.2 Verificar alimentación, control y adquisición de datos ICD validado de PL2 Firmware 3.4.1 Consumo, señales y protocolo comprobados en banco □ 3.4.3 Calibrar sensibilidad, ganancia y rango dinámico Curvas de calibración PL2 Ensayos/EMC 5.2.4 Curvas repetibles con incertidumbre y condiciones registradas □ 3.5 Estructura, paneles y seguridad 3.5.1 Verificar CAD del stack e interfaces mecánicas Modelo CAD integrado Mecánica 2.2.2 Sin colisiones y con separaciones, tornillería y tolerancias definidas □

Página 6 de 15

PocketQube UTN-FRC 2026 PKQ-WBS-001 | Rev. A WBS Paquete / actividad Entregable Responsable Dep. Criterio de cierre OK 3.5.2 Documentar bottom, sliding y laterales Plano de configuración exterior Mecánica 3.5.1 Bottom board, sliding plate, 3 laterales y lateral con antena identificados □ 3.5.3 Verificar batería, killswitches y despliegue de antena Informe de mecanismos de seguridad Mecánica 3.5.2 Retención, liberación y redundancia ensayadas sin daño □ 3.6 Liberación, fabricación y armado 3.6.1 Liberar archivos KiCad, CAD, Gerber y BOM Paquete de fabricación Documentación 3.1.1, 3.2.2, 3.5.1 Archivos revisados, versionados y coherentes con la baseline □ 3.6.2 Fabricar y controlar componentes Informe de recepción e inspección Mecánica 3.6.1 PCB y piezas cumplen dimensiones y revisión requerida □ 3.6.3 Ensamblar el stack de vuelo Unidad integrada Equipo completo 3.6.2 Montaje completo conforme a procedimiento y checklist □

Página 7 de 15

PocketQube UTN-FRC 2026 PKQ-WBS-001 | Rev. A 4 4.0 Software y firmware Desarrollar el software embebido, protocolos, modos operativos y soporte de prueba. Responsable funcional de fase: Firmware WBS Paquete / actividad Entregable Responsable Dep. Criterio de cierre OK 4.1 Arquitectura y configuración 4.1.1 Definir arquitectura de firmware y tareas Software design description Firmware 2.2.4 Módulos, tareas, interfaces y temporización definidos □ 4.1.2 Configurar repositorio, build y versionado Entorno reproducible Firmware 1.3.2 Compilación documentada y binario trazable a un commit □ 4.1.3 Definir telemetría, telecomandos y protocolos Especificación de comunicaciones Firmware 2.2.3 Tramas, unidades, rangos y manejo de errores definidos □ 4.2 Drivers de subsistemas 4.2.1 Implementar drivers de energía y housekeeping Drivers EPS/OBC Firmware 4.1.1 Lecturas y comandos verificados contra banco □ 4.2.2 Implementar driver SX1262 y enlace LoRa Driver de comunicaciones Firmware 3.2.1 TX/RX estable con control de errores y telemetría □ 4.2.3 Implementar sensores y actuadores ADCS Drivers ADCS Firmware 3.3.1 Sensores leídos y magnetorquers accionados de forma controlada □ 4.2.4 Implementar adquisición y control de PL2 Driver PL2 Firmware 3.4.2 Mediciones adquiridas, marcadas temporalmente y almacenadas □ 4.3 Aplicación de vuelo 4.3.1 Implementar máquina de estados y modo seguro Aplicación de vuelo Firmware 4.2.1 Transiciones nominales y de contingencia verificadas □ 4.3.2 Implementar housekeeping, alarmas y recuperación Gestión de fallas Firmware 4.3.1 Límites y acciones de recuperación probados □ 4.3.3 Implementar control ADCS y secuencias de misión Algoritmos de misión ADCS 4.2.3 Secuencias ejecutadas con temporización y saturaciones controladas □ 4.4 Verificación y liberación 4.4.1 Ejecutar pruebas unitarias y análisis estático Informe de pruebas de software Firmware 4.2 Casos críticos cubiertos y defectos severos cerrados □ 4.4.2 Ejecutar pruebas hardware-in-the-loop con EGSE Resultados HIL Firmware 5.1.4 Interfaces y escenarios de falla verificados con hardware □ 4.4.3 Liberar versión candidata de vuelo Binario y release notes Firmware 4.4.1, 4.4.2 Binario identificado, reproducible y aprobado para integración □

Página 8 de 15

PocketQube UTN-FRC 2026 PKQ-WBS-001 | Rev. A 5 5.0 Integración del sistema Poner en marcha cada placa, integrar el stack y establecer una baseline funcional medible. Responsable funcional de fase: Ingeniería de sistemas WBS Paquete / actividad Entregable Responsable Dep. Criterio de cierre OK 5.1 EGSE y banco de pruebas 5.1.1 Preparar alimentación protegida y cargas electrónicas Banco eléctrico Electrónica de potencia 2.2.3 Límites, protecciones y puntos de medición verificados □ 5.1.2 Preparar instrumentación y adquisición de datos Plan de instrumentación Ensayos/EMC 5.1.1 Instrumentos identificados, calibrados y con incertidumbre conocida □ 5.1.3 Diseñar el EGSE integral del PocketQube Arquitectura, planos y procedimientos del EGSE Equipo completo 5.1.1, 5.1.2 El EGSE permite alimentar, estimular, comandar, medir y registrar el comportamiento de EPS, OBC/COMMS, ADCS y payload como sistema completo □ 5.1.4 Construir e integrar la interfaz cableada del EGSE EGSE cableado operativo Electrónica/Ensayos 5.1.3 Alimentación, buses, comandos, telemetría y puntos de medición funcionan mediante una conexión segura y repetible □ 5.1.5 Implementar la interfaz inalámbrica del EGSE mediante las antenas del PocketQube Banco RF y enlace inalámbrico de prueba RF/Comunicaciones 5.1.3, 3.2.1 Enlace TX/RX extremo a extremo verificado usando las antenas del PocketQube, con niveles y tráfico registrados □ 5.2 Bring-up por subsistema 5.2.1 Realizar bring-up de EPS Checklist EPS Electrónica de potencia 5.1.4 Tensiones, protecciones y telemetría dentro de límites □ 5.2.2 Realizar bring-up de OBC/COMMS Checklist OBC/COMMS RF/Comunicaciones 5.1.4 Boot, interfaces y enlace básico operativos □ 5.2.3 Realizar bring-up de ADCS Checklist ADCS ADCS 5.1.4 Sensores y actuadores responden sin sobreconsumo □ 5.2.4 Realizar bring-up de PL2 Checklist PL2 Ensayos/EMC 5.1.4 Adquisición estable y piso de ruido inicial registrado □ 5.3 Integración progresiva 5.3.1 Integrar placas por etapas Stack parcialmente integrado Equipo completo 5.2 Cada incorporación conserva las funciones ya verificadas □ 5.3.2 Verificar interfaces eléctricas, de datos y mecánicas Informe de interfaces Ingeniería de sistemas 5.3.1 Sin incompatibilidades, resets ni interferencias mecánicas críticas □ 5.3.3 Ejecutar prueba funcional del stack completo Baseline funcional Equipo completo 4.4.3, 5.3.2 Modos nominales y seguros completados con registro de datos □

Página 9 de 15

PocketQube UTN-FRC 2026 PKQ-WBS-001 | Rev. A WBS Paquete / actividad Entregable Responsable Dep. Criterio de cierre OK 5.3.4 Ejecutar prueba extremo a extremo del PocketQube completo con el EGSE Informe de prueba integral cableada e inalámbrica Equipo completo 5.1.4, 5.1.5, 5.3.3 El satélite completo es operado y medido en tierra por conexión cableada y por enlace inalámbrico usando sus antenas □ 5.4 Configuración as-built 5.4.1 Registrar configuración, revisiones y números de serie Lista as-built Documentación 5.3.4 Unidad física trazable a archivos y componentes □ 5.4.2 Actualizar presupuestos con valores medidos Budgets actualizados Ingeniería de sistemas 5.3.4 Masa, potencia, datos y márgenes reconciliados □

Página 10 de 15

PocketQube UTN-FRC 2026 PKQ-WBS-001 | Rev. A 6 6.0 Verificación y validación Demostrar mediante evidencia objetiva que el sistema cumple sus requisitos y criterios de aceptación. Responsable funcional de fase: Ensayos/EMC WBS Paquete / actividad Entregable Responsable Dep. Criterio de cierre OK 6.1 Planificación de V&V 6.1.1 Definir plan maestro de verificación Plan V&V Ingeniería de sistemas 2.1.4 Todos los requisitos tienen método, nivel y responsable □ 6.1.2 Cuantificar criterios de aceptación Matriz de aceptación Ingeniería de sistemas 6.1.1 Criterios numéricos y reglas de pass/fail aprobados □ 6.1.3 Definir configuración e instrumentación de ensayo Procedimientos de ensayo Ensayos/EMC 6.1.2 Configuración, instrumentos y datos requeridos definidos □ 6.2 Pruebas funcionales y eléctricas 6.2.1 Verificar modos, comandos y recuperación Informe funcional Firmware 5.3.3 Secuencias completas sin fallas no explicadas □ 6.2.2 Verificar batería, protecciones y killswitches Informe de seguridad eléctrica Electrónica de potencia 3.5.3 Inhibición, encendido y protecciones cumplen criterios □ 6.2.3 Ejecutar ensayo de autonomía y operación prolongada Informe de endurance Equipo completo 6.2.1 Operación sostenida sin degradación ni reset no previsto □ 6.3 Pruebas RF y comunicaciones 6.3.1 Medir S11, ROE y ancho de banda de antena Informe de adaptación RF/Comunicaciones 3.2.3 Resultados comparados con límites y configuración de montaje □ 6.3.2 Medir potencia, sensibilidad y alcance Informe de enlace RF/Comunicaciones 6.3.1 Margen de enlace reconciliado con mediciones □ 6.3.3 Medir espectro y armónicos del transmisor Informe de emisiones RF Ensayos/EMC 6.3.2 Armónicos, incluido 1736 MHz, cuantificados □ 6.4 Pruebas ADCS 6.4.1 Verificar calibración y ruido de sensores Informe de sensores ADCS ADCS 3.3.3 Sesgo, ruido, deriva y desalineación cuantificados □ 6.4.2 Verificar actuación y detumbling Informe de control ADCS ADCS 6.4.1 Momento magnético y tiempo de estabilización medidos o correlacionados □ 6.5 Pruebas mecánicas y ambientales 6.5.1 Verificar masa, dimensiones y centro de gravedad Informe dimensional y de masa Mecánica 3.6.3 Unidad dentro de envolvente y presupuesto aprobados □ 6.5.2 Ejecutar vibración o correlación modal Informe de vibración Mecánica 6.5.1 Integridad y frecuencias naturales verificadas □ 6.5.3 Ejecutar ensayo térmico disponible Informe térmico Mecánica 6.5.1 Temperaturas y funcionamiento dentro de límites □

Página 11 de 15

PocketQube UTN-FRC 2026 PKQ-WBS-001 | Rev. A WBS Paquete / actividad Entregable Responsable Dep. Criterio de cierre OK 6.6 Aceptación del sistema 6.6.1 Cerrar matriz de trazabilidad RTM con evidencias Ingeniería de sistemas 6.2, 6.3, 6.4, 6.5 Requisitos verificados o desviaciones formalmente aceptadas □ 6.6.2 Cerrar anomalías y acciones correctivas Registro de anomalías cerrado Equipo completo 6.6.1 Sin anomalías críticas abiertas □ 6.6.3 Emitir informe de aceptación Informe de aceptación Ingeniería de sistemas 6.6.2 Resultado global aprobado por el equipo □

Página 12 de 15

PocketQube UTN-FRC 2026 PKQ-WBS-001 | Rev. A 7 7.0 EMC y mejora de PL2 Identificar interferencias internas sobre el radiómetro PL2, aplicar una mejora y demostrar el cambio antes/después. Responsable funcional de fase: Ensayos/EMC WBS Paquete / actividad Entregable Responsable Dep. Criterio de cierre OK 7.1 Baseline electromagnética 7.1.1 Medir piso de ruido de PL2 aislado Espectro baseline PL2 Ensayos/EMC 3.4.3 Piso de ruido repetible con incertidumbre registrada □ 7.1.2 Definir matriz de modos encendido/apagado Matriz de ensayos EMC Ensayos/EMC 5.3.3 Combinaciones EPS, LoRa, ADCS y PL2 cubiertas □ 7.1.3 Medir emisiones conducidas y radiadas Dataset EMC baseline Ensayos/EMC 7.1.1, 7.1.2 Espectros y condiciones sincronizados por modo □ 7.2 Identificación de fuentes 7.2.1 Caracterizar ruido de EPS y MPPT Mapa de interferencia EPS Electrónica de potencia 7.1.3 Picos asociados a conversores identificados y cuantificados □ 7.2.2 Caracterizar LoRa y armónico de 1736 MHz Mapa de interferencia COMMS RF/Comunicaciones 7.1.3 Acoplamiento del fundamental y armónicos sobre PL2 cuantificado □ 7.2.3 Caracterizar relojes, buses y actividad digital Mapa de interferencia digital Firmware 7.1.3 Líneas espectrales correlacionadas con señales digitales □ 7.2.4 Caracterizar ADCS y magnetorquers Mapa de interferencia ADCS ADCS 7.1.3 Transitorios y acoplamientos durante actuación cuantificados □ 7.3 Diseño de mitigaciones 7.3.1 Diseñar filtrado de alimentación y retornos Propuesta de filtro y GND Electrónica de potencia 7.2.1 Pérdidas, estabilidad y atenuación estimadas □ 7.3.2 Diseñar mitigación RF, layout o blindaje Propuesta RF/PCB RF/Comunicaciones 7.2.2 Atenuación prevista sin degradar el enlace □ 7.3.3 Implementar ventana silenciosa por firmware Secuencia quiet mode Firmware 7.2.3, 7.2.4 PL2 mide con emisores seleccionados temporalmente inactivos □ 7.3.4 Seleccionar e implementar la mejora Prototipo modificado Equipo completo 7.3.1, 7.3.2, 7.3.3 Cambio elegido mediante evidencia, riesgo y costo □ 7.4 Verificación de la mejora 7.4.1 Repetir ensayos antes/después Dataset comparativo Ensayos/EMC 7.3.4 Mismas condiciones y configuración documentadas □ 7.4.2 Cuantificar mejora e incertidumbre Análisis estadístico EMC Ensayos/EMC 7.4.1 Reducción de ruido y efecto sobre desempeño expresados numéricamente □ 7.4.3 Actualizar diseño, requisitos e informe EMC Informe técnico de mejora Ingeniería de sistemas 7.4.2 Resultados trazados a cambios y criterios de aceptación □

Página 13 de 15

PocketQube UTN-FRC 2026 PKQ-WBS-001 | Rev. A 8 8.0 Documentación y cierre Consolidar revisiones, evidencias, entregables académicos y lecciones aprendidas. Responsable funcional de fase: Documentación WBS Paquete / actividad Entregable Responsable Dep. Criterio de cierre OK 8.1 Revisiones técnicas 8.1.1 Preparar y realizar PDR Paquete PDR y acta Ingeniería de sistemas 2.3 Arquitectura y plan de verificación aprobados □ 8.1.2 Preparar y realizar CDR Paquete CDR y acta Ingeniería de sistemas 3.6.1, 4.1 Diseño detallado liberado para integración □ 8.1.3 Preparar y realizar TRR Paquete TRR y acta Ensayos/EMC 6.1.3 Procedimientos, unidad e instrumentación listos □ 8.1.4 Preparar revisión final Paquete de revisión final Líder de proyecto 6.6.3, 7.4.3 Cumplimiento, desviaciones y conclusiones aprobados □ 8.2 Documentación técnica 8.2.1 Consolidar memoria de diseño y decisiones Design history file Documentación 8.1.2 Decisiones y cambios vinculados a requisitos y revisiones □ 8.2.2 Consolidar BOM, planos, esquemáticos y software Paquete de datos técnicos Documentación 5.4.1 Archivos finales coherentes con la unidad as-built □ 8.2.3 Consolidar informes y datos de ensayo Repositorio de evidencias Ensayos/EMC 6.6.3 Datos, scripts, calibraciones e informes auditables □ 8.2.4 Redactar manual de integración y operación Manual técnico Documentación 5.3.3 Procedimientos reproducibles y advertencias de seguridad incluidas □ 8.3 Entrega académica y cierre 8.3.1 Redactar informe de avance Informe de avance Equipo completo 1.4.3 Estado, resultados parciales y próximos pasos documentados □ 8.3.2 Redactar informe técnico final Trabajo final/PPS Equipo completo 8.2.1, 8.2.3 Objetivos, metodología, resultados y conclusiones completos □ 8.3.3 Preparar presentación y defensa Presentación final Equipo completo 8.3.2 Relato técnico ensayado y preguntas críticas preparadas □ 8.3.4 Archivar baseline y lecciones aprendidas Cierre de proyecto Líder de proyecto 8.3.3 Repositorio congelado, pendientes transferidos y lecciones registradas □

Página 14 de 15

PocketQube UTN-FRC 2026 | PKQ-WBS-001 | Rev. A

## Criterios para aprobar la línea base WBS

1. La configuración de vuelo y las exclusiones están confirmadas por los responsables del diseño original.
2. Cada paquete de nivel 3 tiene responsable nominal, duración, dependencia y evidencia esperada.
3. Los presupuestos de masa, potencia, datos y enlace poseen margen y fuente trazable.
4. La matriz V&V cubre cada requisito y referencia un procedimiento o análisis.
5. El plan EMC separa baseline, identificación de fuentes, mitigación y comparación antes/después.
6. Los hitos PDR, CDR, TRR y revisión final poseen criterios de entrada y salida.

Fin del documento - PKQ-WBS-001 Rev. A

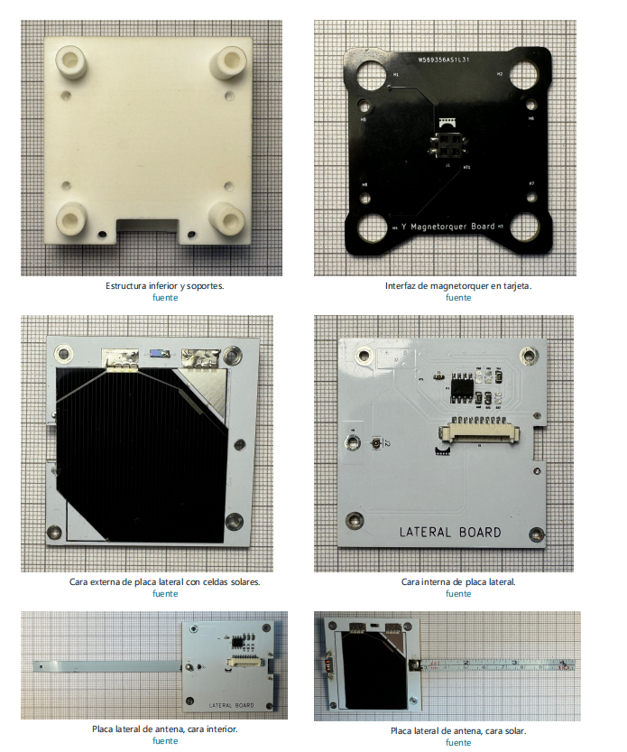
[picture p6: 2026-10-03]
06_Miscelaneas/imagenes/Placas-2.png

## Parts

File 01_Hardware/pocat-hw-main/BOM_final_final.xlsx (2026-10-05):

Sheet: EPS
PQ_EPS — BOM preparada
Datos del RAR revisado. DOCUMENTADO = MPN del proyecto. PROPUESTO / REVISAR = selección pendiente de aprobación técnica. EXCLUIR = no comprar/montar. Cantidades por placa.
Line # | Reference Designator | Qty | Value / Description | Manufacturer | Manufacturer Part Number | Package / Footprint | Type (SMD/THT) | Status | Instructions / Notes | Source
2 | C1 | 1 | 2.2u | Murata | GRM155R61C225KE11D | 0603 (1608 Metric); C_0603_1608Metric | SMD | DOCUMENTADO |  | PQ_EPS.kicad_sch + PQ_EPS.kicad_pcb https://www.murata.com/en-us/products/productdetail?partno=GRM155R61C225KE11D
3 | C2 | 1 | 10u | Murata | GRM188R61A106KAALD | 0603 (1608 Metric); C_0603_1608Metric | SMD | DOCUMENTADO | MPN documentado en el proyecto; huella recuperada del PCB. | PQ_EPS.kicad_sch + PQ_EPS.kicad_pcb https://www.mouser.com/ProductDetail/Murata-Electronics/GRM188R61A106KAALD
4 | C3 | 1 | 100u | Murata | GRM21BR60J107ME15K | 1206 (3216 Metric); C_1206_3216Metric | SMD | DOCUMENTADO |  | PQ_EPS.kicad_sch + PQ_EPS.kicad_pcb
5 | C4 | 1 | 0.1u | KEMET | C0603C104K8PACTU | 0603 (1608 Metric); C_0603_1608Metric | SMD | DOCUMENTADO | MPN documentado en el proyecto; huella recuperada del PCB. | PQ_EPS.kicad_sch + PQ_EPS.kicad_pcb https://www.digikey.com/en/products/detail/kemet/C0603C104K8PACTU/8572408
6 | C5 | 1 | 22u | Murata | GRM187R61A226ME15J | 0603 (1608 Metric); C_0603_1608Metric | SMD | DOCUMENTADO | MPN documentado en el proyecto; huella recuperada del PCB. | PQ_EPS.kicad_sch + PQ_EPS.kicad_pcb https://www.murata-electronics.com/GRM187R61A226ME15J/10095848
7 | CF1,CF2,CF3 | 3 | 1u | Murata | GRM155R61C105KA12D | 0603 (1608 Metric); C_0603_1608Metric | SMD | DOCUMENTADO |  | PQ_EPS.kicad_sch + PQ_EPS.kicad_pcb
8 | CIN1,CIN2,CIN3 | 3 | 1.5u | TDK | C1005X5R1V155K050BC | 0603 (1608 Metric); C_0603_1608Metric | SMD | DOCUMENTADO |  | PQ_EPS.kicad_sch + PQ_EPS.kicad_pcb https://product.tdk.com/en/search/capacitor/ceramic/mlcc/info?part_no=C1005X5R1V155K050BC
9 | CINSNS1 | 1 | 1n | Murata | GRM155R61A102KA01D | 0603 (1608 Metric); C_0603_1608Metric | SMD | DOCUMENTADO |  | PQ_EPS.kicad_sch + PQ_EPS.kicad_pcb + recovered-footprints.json
10 | CINSNS2 | 1 | 1n | Murata | GRM155R61A102KA01D | 0603 (1608 Metric); C_0603_1608Metric | SMD | DOCUMENTADO |  | PQ_EPS.kicad_sch + PQ_EPS.kicad_pcb + recovered-footprints.json
11 | CINSNS3 | 1 | 1n | Murata | GRM155R61A102KA01D | 0603 (1608 Metric); C_0603_1608Metric | SMD | DOCUMENTADO |  | PQ_EPS.kicad_sch + PQ_EPS.kicad_pcb + recovered-footprints.json
12 | COUT1 | 1 | 10u | Murata | GRM188R61A106KAALD | 0603 (1608 Metric); C_0603_1608Metric | SMD | DOCUMENTADO |  | PQ_EPS.kicad_sch + PQ_EPS.kicad_pcb + recovered-footprints.json https://www.mouser.com/ProductDetail/Murata-Electronics/GRM188R61A106KAALD
13 | COUT2,COUT3 | 2 | 10u | Murata | GRM188R61A106KAALD | 0603 (1608 Metric); C_0603_1608Metric | SMD | DOCUMENTADO | MPN documentado en el proyecto; huella recuperada del PCB. | PQ_EPS.kicad_sch + PQ_EPS.kicad_pcb https://www.mouser.com/ProductDetail/Murata-Electronics/GRM188R61A106KAALD
14 | COUTSNS1 | 1 | 1n | Murata | GRM155R61A102KA01D | 0603 (1608 Metric); C_0603_1608Metric | SMD | DOCUMENTADO |  | PQ_EPS.kicad_sch + PQ_EPS.kicad_pcb + recovered-footprints.json
15 | COUTSNS2 | 1 | 1n | Murata | GRM155R61A102KA01D | 0603 (1608 Metric); C_0603_1608Metric | SMD | DOCUMENTADO |  | PQ_EPS.kicad_sch + PQ_EPS.kicad_pcb + recovered-footprints.json
16 | COUTSNS3 | 1 | 1n | Murata | GRM155R61A102KA01D | 0603 (1608 Metric); C_0603_1608Metric | SMD | DOCUMENTADO |  | PQ_EPS.kicad_sch + PQ_EPS.kicad_pcb + recovered-footprints.json
17 | D1,D2,D3 | 3 | SMM4F | STMicroelectronics | SMM4F18A-TR | STmite Flat; huella SMM4F15ATR; SMM4F15ATR | SMD | DOCUMENTADO |  | PQ_EPS.kicad_sch + PQ_EPS.kicad_pcb
18 | D4,D5,D6 | 3 | shottky | ROHM Semiconductor | RBS1LAM40ATR | SOD-128 (PMDTM); RBS1LAM40ATR_Schottky | SMD | DOCUMENTADO | MPN documentado en el proyecto; huella recuperada del PCB. | PQ_EPS.kicad_sch + PQ_EPS.kicad_pcb https://www.rohm.com/products/diodes/schottky-barrier-diodes/ultra-low-vf/rbs1lam40a-product
19 | DNC1,DNC2 | 2 | 20k | Panasonic | ERJ-UP3J203V | 0603 (1608 Metric); R_0603_1608Metric | SMD | DOCUMENTADO | MPN documentado en el proyecto; huella recuperada del PCB. | PQ_EPS.kicad_sch + PQ_EPS.kicad_pcb
21 | IC1 | 1 | DS2782E+ | Analog Devices | DS2782E+ | TSSOP-8 4.4x3mm P0.65mm; TSSOP-8_4.4x3mm_P0.65mm | SMD | DOCUMENTADO | MPN documentado en el proyecto; huella recuperada del PCB. | PQ_EPS.kicad_sch + PQ_EPS.kicad_pcb https://www.analog.com/media/en/technical-documentation/data-sheets/DS2782.pdf
22 | IC2 | 1 | ISL9120IRTNZ | Renesas / Intersil | ISL9120IRTNZ | TQFN-12, 3 x 3 mm; ISL9120IRTNZ | SMD | DOCUMENTADO | MPN documentado en el proyecto; huella recuperada del PCB. | PQ_EPS.kicad_sch + PQ_EPS.kicad_pcb https://www.renesas.com/en/products/isl9120/part-details/isl9120irtnz
23 | J1,J2,J3,J4 | 4 | CES-110-02-L-S | Samtec | CES-110-02-L-S | Socket 1x10, paso 2.54 mm; SLW-110-01 | THT | DOCUMENTADO | MPN documentado en el proyecto; huella recuperada del PCB. | PQ_EPS.kicad_sch + PQ_EPS.kicad_pcb
24 | J5 | 1 | CES-102-02 | Samtec | CES-102-02-L-S | Socket 1x2, paso 2.54 mm; CES-102-02 | THT | DOCUMENTADO | Modelo propuesto según huella CES-102-02. Confirmar altura y acabado. | PQ_EPS.kicad_sch + PQ_EPS.kicad_pcb https://www.samtec.com/products/ces-102-02-l-s
25 | L1,L2,L3 | 3 | 10u | Murata | LQH2MPZ100MGRL | 0805 (2012 Metric); L_0805_2012Metric | SMD | DOCUMENTADO | Inductor de cuerpo 2.0 x 1.6 mm sobre huella L_0805: comparar land pattern del fabricante. | PQ_EPS.kicad_sch + PQ_EPS.kicad_pcb https://www.digikey.com/en/products/detail/murata-electronics/LQH2MPZ100MGRL/6799349
26 | L4 | 1 | 2.2u | Coilcraft | XAL5030-222MEC | XAL5030, huella específica 5 x 5 mm; XAL5030222MEC | SMD | DOCUMENTADO | MPN documentado en el proyecto; huella recuperada del PCB. | PQ_EPS.kicad_sch + PQ_EPS.kicad_pcb
27 | L5 | 1 | 1u | TDK | TFM201610GHM-1R0MTAA | 0805 (2012 Metric); L_0805_2012Metric | SMD | DOCUMENTADO | MPN discordantes en el proyecto: TFM201610GHM1R0A, TFM201610GHM-1R0MTAA. Inductor de cuerpo 2.0 x 1.6 mm sobre huella L_0805: comparar land pattern del fabricante. | PQ_EPS.kicad_sch + PQ_EPS.kicad_pcb https://www.digikey.com/en/products/detail/tdk/TFM201610GHM-1R0MTAA/5773536
28 | Q1 | 1 | SIR424DP | Vishay | SIR424DP-T1-GE3 | PowerPAK SO-8; SIR424DP | SMD | DOCUMENTADO | MPN documentado en el proyecto; huella recuperada del PCB. | PQ_EPS.kicad_sch + PQ_EPS.kicad_pcb https://www.vishay.com/en/product/64830/
29 | R1,R2,R3,R8 | 4 | 1k | YAGEO | RC0603FR-071KL | 0603 (1608 Metric); R_0603_1608Metric | SMD | DOCUMENTADO | Propuesta: 1%; confirmar potencia y TCR. | PQ_EPS.kicad_sch + PQ_EPS.kicad_pcb https://www.yageogroup.com/component-documentation/download/specsheet/RC0603FR-071KL
30 | R4 | 1 | 75m | KOA Speer | UR73V2ATTD75L0F | 0805 (2012 Metric); R_0805_2012Metric | SMD | DOCUMENTADO | MPN documentado en el proyecto; huella recuperada del PCB. | PQ_EPS.kicad_sch + PQ_EPS.kicad_pcb https://www.digikey.com/en/products/detail/koa-speer-electronics-inc/UR73V2ATTD75L0F/9845704
31 | R6 | 1 | 2k | YAGEO | RC0603FR-072KL | 0603 (1608 Metric); R_0603_1608Metric | SMD | DOCUMENTADO | Propuesta: 1%; confirmar potencia y TCR. | PQ_EPS.kicad_sch + PQ_EPS.kicad_pcb https://www.yageogroup.com/component-documentation/download/specsheet/RC0603FR-072KL
32 | R7 | 1 | 510 | YAGEO | RC0603FR-07510RL | 0603 (1608 Metric); R_0603_1608Metric | SMD | DOCUMENTADO | Propuesta: 1%; confirmar potencia y TCR. | PQ_EPS.kicad_sch + PQ_EPS.kicad_pcb https://www.yageogroup.com/component-documentation/download/specsheet/RC0603FR-07510RL
33 | R9 | 1 | 15m | Vishay Dale | WSL0603R0150FEA | 0603 (1608 Metric); R_0603_1608Metric | SMD | DOCUMENTADO | Shunt propuesto: 15 mΩ, 1%, 0.1 W. Confirmar corriente, disipación y calibración. | PQ_EPS.kicad_sch + PQ_EPS.kicad_pcb https://www.vishay.com/docs/30100/wsl.pdf
34 | RBIAS1 | 1 | 10k | YAGEO | RC0603FR-0710KL | 0603 (1608 Metric); R_0603_1608Metric | SMD | DOCUMENTADO | Propuesta: 1%; confirmar potencia y TCR. | PQ_EPS.kicad_sch + PQ_EPS.kicad_pcb https://www.yageogroup.com/component-documentation/download/specsheet/RC0603FR-0710KL
35 | RF1,RF2,RF3,RF4,RF5,RF6 | 6 | 1k | Vishay / Dale | CRCW04021K00FKEDHP | 0603 (1608 Metric); R_0603_1608Metric | SMD | DOCUMENTADO |  | PQ_EPS.kicad_sch + PQ_EPS.kicad_pcb https://www.digikey.com/en/products/detail/vishay-dale/CRCW04021K00FKEDHP/2222518
36 | RFB1 | 1 | 68k | KOA Speer | SG73P1ETTP6802F | 0603 (1608 Metric); R_0603_1608Metric | SMD | DOCUMENTADO |  | PQ_EPS.kicad_sch + PQ_EPS.kicad_pcb https://www.yageogroup.com/component-documentation/download/specsheet/RC0603FR-0768KL
37 | RFB2 | 1 | 255k | Panasonic | ERJ-U02F2553X | 0402 (1005 Metric); R_0402_1005Metric | SMD | DOCUMENTADO | MPN documentado en el proyecto; huella recuperada del PCB. | PQ_EPS.kicad_sch + PQ_EPS.kicad_pcb https://www.digikey.com/en/products/detail/panasonic-industry/ERJ-U02F2553X/11631521
38 | RFG0,RFG1,RFG2 | 3 | 1k | Vishay / Thin Film | PCAN0805E1001BST5 | 0603 (1608 Metric); R_0603_1608Metric | SMD | DOCUMENTADO |  | PQ_EPS.kicad_sch + PQ_EPS.kicad_pcb https://www.digikey.com/en/products/detail/vishay-dale-thin-film/PCAN0805E1001BST5/6003287
39 | RFV0,RFV1,RFV2 | 3 | 1k | Vishay / Thin Film | PCAN0805E1001BST5 | 0603 (1608 Metric); R_0603_1608Metric | SMD | DOCUMENTADO |  | PQ_EPS.kicad_sch + PQ_EPS.kicad_pcb https://www.digikey.com/en/products/detail/vishay-dale-thin-film/PCAN0805E1001BST5/6003287
40 | RH1,RH2,RH3 | 3 | 910k | Panasonic | ERJ-PA3F9103V | 0603 (1608 Metric); R_0603_1608Metric | SMD | DOCUMENTADO | MPN documentado en el proyecto; huella recuperada del PCB. | PQ_EPS.kicad_sch + PQ_EPS.kicad_pcb https://www.digikey.com/es/models/5035966
41 | RL1,RL2,RL3 | 3 | 360k | Panasonic | ERJ-UP3F3603V | 0603 (1608 Metric); R_0603_1608Metric | SMD | DOCUMENTADO | MPN documentado en el proyecto; huella recuperada del PCB. | PQ_EPS.kicad_sch + PQ_EPS.kicad_pcb https://www.digikey.co.uk/en/products/detail/panasonic-industry/ERJ-UP3F3603V/12092556
42 | RPF1 | 1 | 147k | Panasonic | ERJ-P03F1473V | 0603 (1608 Metric); R_0603_1608Metric | SMD | DOCUMENTADO | MPN documentado en el proyecto; huella recuperada del PCB. | PQ_EPS.kicad_sch + PQ_EPS.kicad_pcb
43 | RPF2 | 1 | 68k | KOA Speer | SG73P1ETTP6802F | 0603 (1608 Metric); R_0603_1608Metric | SMD | DOCUMENTADO |  | PQ_EPS.kicad_sch + PQ_EPS.kicad_pcb https://www.yageogroup.com/component-documentation/download/specsheet/RC0603FR-0768KL
44 | RP_CHRG1 | 1 | 5k | Vishay / Dale | CRCW08055K00JNTA | 0805 (2012 Metric); R_0805_2012Metric | SMD | DOCUMENTADO | MPN documentado en el proyecto; huella recuperada del PCB. | PQ_EPS.kicad_sch + PQ_EPS.kicad_pcb https://www.digikey.com/en/products/detail/vishay-dale/CRCW08055K00JNTA/5075662
45 | RP_FAULT1 | 1 | 5k | Vishay / Dale | CRCW08055K00JNTA | 0805 (2012 Metric); R_0805_2012Metric | SMD | DOCUMENTADO | MPN documentado en el proyecto; huella recuperada del PCB. | PQ_EPS.kicad_sch + PQ_EPS.kicad_pcb https://www.digikey.com/en/products/detail/vishay-dale/CRCW08055K00JNTA/5075662
46 | RS1,RS2,RS3 | 3 | 300m | ROHM Semiconductor | UCR03EVPFLR300 | 0603 (1608 Metric); R_0603_1608Metric | SMD | DOCUMENTADO | MPN documentado en el proyecto; huella recuperada del PCB. | PQ_EPS.kicad_sch + PQ_EPS.kicad_pcb
47 | U1,U2,U3 | 3 | SPV1040TTR | STMicroelectronics | SPV1040TTR | TSSOP-8 4.4x3mm P0.65mm; TSSOP-8_4.4x3mm_P0.65mm | SMD | DOCUMENTADO | MPN documentado en el proyecto; huella recuperada del PCB. | PQ_EPS.kicad_sch + PQ_EPS.kicad_pcb https://www.digikey.com/en/products/detail/stmicroelectronics/SPV1040TTR/2672694
48 | U4 | 1 | LTC4040IUFD#PBF | Analog Devices | LTC4040IUFD#PBF | QFN-24-1EP 4x5mm P0.5mm EP2.65x3.65mm; QFN-24-1EP_4x5mm_P0.5mm_EP2.65x3.65mm | SMD | DOCUMENTADO | MPN documentado en el proyecto; huella recuperada del PCB. | PQ_EPS.kicad_sch + PQ_EPS.kicad_pcb https://www.digikey.com/en/products/detail/analog-devices-inc/LTC4040IUFD-PBF/5297618

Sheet: EGSE
EGSE — BOM preparada
Datos del RAR revisado. DOCUMENTADO = MPN del proyecto. PROPUESTO / REVISAR = selección pendiente de aprobación técnica. EXCLUIR = no comprar/montar. Cantidades por placa.
Line # | Reference Designator | Qty | Value / Description | Manufacturer | Manufacturer Part Number | Package / Footprint | Type (SMD/THT) | Status | Instructions / Notes | Source
5 | C1 | 1 | 2.2u | Murata | GRM155R61C225KE11D | 0603 (1608 Metric); C_0603_1608Metric | SMD | DOCUMENTADO |  | EGSE.kicad_sch + EGSE.kicad_pcb
6 | C2 | 1 | 10u | Murata | GRM188R61A106KAALD | 0603 (1608 Metric); C_0603_1608Metric | SMD | DOCUMENTADO | MPN documentado en el proyecto; huella recuperada del PCB. | EGSE.kicad_sch + EGSE.kicad_pcb
7 | C3 | 1 | 100u | Murata | GRM21BR60J107ME15K | 1206 (3216 Metric); C_1206_3216Metric | SMD | DOCUMENTADO |  | EGSE.kicad_sch + EGSE.kicad_pcb
8 | C4 | 1 | 22u | Murata | GRM187R61A226ME15J | 0603 (1608 Metric); C_0603_1608Metric | SMD | DOCUMENTADO | MPN documentado en el proyecto; huella recuperada del PCB. | EGSE.kicad_sch + EGSE.kicad_pcb
9 | C5 | 1 | 10u | Murata | GRM188R61A106KAALD | 0603 (1608 Metric); C_0603_1608Metric | SMD | DOCUMENTADO | MPN documentado en el proyecto; huella recuperada del PCB. | EGSE.kicad_sch + EGSE.kicad_pcb
10 | D1,D2,D3 | 3 | RBS1LAM40ATR | ROHM Semiconductor | RBS1LAM40ATR | SOD-128 (PMDTM); RBS1LAM40ATR_Schottky | SMD | DOCUMENTADO | MPN documentado en el proyecto; huella recuperada del PCB. | EGSE.kicad_sch + EGSE.kicad_pcb
11 | F1 | 1 | SF-1206S080-2 | Bourns | SF-1206S080-2 | FUSC3116X70N | SMD | DOCUMENTADO | MPN documentado en el proyecto; huella recuperada del PCB. | EGSE.kicad_sch + EGSE.kicad_pcb
34 | IC1 | 1 | ISL9120IRTNZ | Renesas / Intersil | ISL9120IRTNZ | TQFN-12, 3 x 3 mm; ISL9120IRTNZ | SMD | DOCUMENTADO | MPN documentado en el proyecto; huella recuperada del PCB. | EGSE.kicad_sch + EGSE.kicad_pcb
35 | J1 | 1 | CES-110-02-L-S | Samtec | CES-110-02-L-S | PinSocket 1x10 P2.54mm Vertical; PinSocket_1x10_P2.54mm_Vertical | THT | DOCUMENTADO | MPN documentado en el proyecto; huella recuperada del PCB. | EGSE.kicad_sch + EGSE.kicad_pcb
36 | J2 | 1 | CES-110-02-L-S | Samtec | CES-110-02-L-S | PinSocket 1x10 P2.54mm Vertical; PinSocket_1x10_P2.54mm_Vertical | THT | DOCUMENTADO | MPN documentado en el proyecto; huella recuperada del PCB. | EGSE.kicad_sch + EGSE.kicad_pcb
37 | J3 | 1 | CES-110-02-L-S | Samtec | CES-110-02-L-S | PinSocket 1x10 P2.54mm Vertical; PinSocket_1x10_P2.54mm_Vertical | THT | DOCUMENTADO | MPN documentado en el proyecto; huella recuperada del PCB. | EGSE.kicad_sch + EGSE.kicad_pcb
38 | J4 | 1 | CES-110-02-L-S | Samtec | CES-110-02-L-S | PinSocket 1x10 P2.54mm Vertical; PinSocket_1x10_P2.54mm_Vertical | THT | DOCUMENTADO | MPN documentado en el proyecto; huella recuperada del PCB. | EGSE.kicad_sch + EGSE.kicad_pcb
39 | J5 | 1 | CES-110-02-L-S | Samtec | CES-110-02-L-S | PinSocket 1x10 P2.54mm Vertical; PinSocket_1x10_P2.54mm_Vertical | THT | DOCUMENTADO | MPN documentado en el proyecto; huella recuperada del PCB. | EGSE.kicad_sch + EGSE.kicad_pcb
40 | J6 | 1 | CES-110-02-L-S | Samtec | CES-110-02-L-S | PinSocket 1x10 P2.54mm Vertical; PinSocket_1x10_P2.54mm_Vertical | THT | DOCUMENTADO | MPN documentado en el proyecto; huella recuperada del PCB. | EGSE.kicad_sch + EGSE.kicad_pcb
41 | J7 | 1 | CES-110-02-L-S | Samtec | CES-110-02-L-S | PinSocket 1x10 P2.54mm Vertical; PinSocket_1x10_P2.54mm_Vertical | THT | DOCUMENTADO | MPN documentado en el proyecto; huella recuperada del PCB. | EGSE.kicad_sch + EGSE.kicad_pcb
42 | J8 | 1 | CES-110-02-L-S | Samtec | CES-110-02-L-S | PinSocket 1x10 P2.54mm Vertical; PinSocket_1x10_P2.54mm_Vertical | THT | DOCUMENTADO | MPN documentado en el proyecto; huella recuperada del PCB. | EGSE.kicad_sch + EGSE.kicad_pcb
43 | J9 | 1 | CES-110-02-L-S | Samtec | CES-110-02-L-S | PinSocket 1x10 P2.54mm Vertical; PinSocket_1x10_P2.54mm_Vertical | THT | DOCUMENTADO | MPN documentado en el proyecto; huella recuperada del PCB. | EGSE.kicad_sch + EGSE.kicad_pcb
44 | J10 | 1 | CES-110-02-L-S | Samtec | CES-110-02-L-S | PinSocket 1x10 P2.54mm Vertical; PinSocket_1x10_P2.54mm_Vertical | THT | DOCUMENTADO | MPN documentado en el proyecto; huella recuperada del PCB. | EGSE.kicad_sch + EGSE.kicad_pcb
45 | J11 | 1 | CES-110-02-L-S | Samtec | CES-110-02-L-S | PinSocket 1x10 P2.54mm Vertical; PinSocket_1x10_P2.54mm_Vertical | THT | DOCUMENTADO | MPN documentado en el proyecto; huella recuperada del PCB. | EGSE.kicad_sch + EGSE.kicad_pcb
46 | J12 | 1 | CES-110-02-L-S | Samtec | CES-110-02-L-S | PinSocket 1x10 P2.54mm Vertical; PinSocket_1x10_P2.54mm_Vertical | THT | DOCUMENTADO | MPN documentado en el proyecto; huella recuperada del PCB. | EGSE.kicad_sch + EGSE.kicad_pcb
47 | J13 | 1 | TLW-110-05-T-S | SAMTEC | HTSW-110-07-G-S | HDRV10W64P0X254 1X10 2540X248X838P; HDRV10W64P0X254_1X10_2540X248X838P | THT | DOCUMENTADO |  | EGSE.kicad_sch + EGSE.kicad_pcb
48 | J14 | 1 | TLW-110-05-T-S | SAMTEC | HTSW-110-07-G-S | HDRV10W64P0X254 1X10 2540X248X838P; HDRV10W64P0X254_1X10_2540X248X838P | THT | DOCUMENTADO |  | EGSE.kicad_sch + EGSE.kicad_pcb
49 | J15 | 1 | TLW-110-05-T-S | SAMTEC | HTSW-110-07-G-S | HDRV10W64P0X254 1X10 2540X248X838P; HDRV10W64P0X254_1X10_2540X248X838P | THT | DOCUMENTADO |  | EGSE.kicad_sch + EGSE.kicad_pcb
50 | J16 | 1 | TLW-110-05-T-S | SAMTEC | TLW-110-05-T-S | HDRV10W64P0X254 1X10 2540X248X838P; HDRV10W64P0X254_1X10_2540X248X838P | THT | DOCUMENTADO |  | EGSE.kicad_sch + EGSE.kicad_pcb
51 | J17 | 1 | TLW-110-05-T-S | SAMTEC | TLW-110-05-T-S | HDRV10W64P0X254 1X10 2540X248X838P; HDRV10W64P0X254_1X10_2540X248X838P | THT | DOCUMENTADO |  | EGSE.kicad_sch + EGSE.kicad_pcb
52 | J18 | 1 | TLW-110-05-T-S | SAMTEC | TLW-110-05-T-S | HDRV10W64P0X254 1X10 2540X248X838P; HDRV10W64P0X254_1X10_2540X248X838P | THT | DOCUMENTADO |  | EGSE.kicad_sch + EGSE.kicad_pcb
53 | J19 | 1 | TLW-110-05-T-S | SAMTEC | TLW-110-05-T-S | HDRV10W64P0X254 1X10 2540X248X838P; HDRV10W64P0X254_1X10_2540X248X838P | THT | DOCUMENTADO |  | EGSE.kicad_sch + EGSE.kicad_pcb
54 | J20 | 1 | TLW-110-05-T-S | SAMTEC | TLW-110-05-T-S | HDRV10W64P0X254 1X10 2540X248X838P; HDRV10W64P0X254_1X10_2540X248X838P | THT | DOCUMENTADO |  | EGSE.kicad_sch + EGSE.kicad_pcb
55 | J21 | 1 | TLW-110-05-T-S | SAMTEC | TLW-110-05-T-S | HDRV10W64P0X254 1X10 2540X248X838P; HDRV10W64P0X254_1X10_2540X248X838P | THT | DOCUMENTADO |  | EGSE.kicad_sch + EGSE.kicad_pcb
56 | J22 | 1 | TLW-110-05-T-S | SAMTEC | TLW-110-05-T-S | HDRV10W64P0X254 1X10 2540X248X838P; HDRV10W64P0X254_1X10_2540X248X838P | THT | DOCUMENTADO |  | EGSE.kicad_sch + EGSE.kicad_pcb
57 | J23 | 1 | TLW-110-05-T-S | SAMTEC | TLW-110-05-T-S | HDRV10W64P0X254 1X10 2540X248X838P; HDRV10W64P0X254_1X10_2540X248X838P | THT | DOCUMENTADO |  | EGSE.kicad_sch + EGSE.kicad_pcb
58 | J24 | 1 | HTSW-110-07-G-S | SAMTEC | HTSW-110-07-G-S | HDRV10W64P0X254 1X10 2540X248X838P; HDRV10W64P0X254_1X10_2540X248X838P | THT | DOCUMENTADO | MPN documentado en el proyecto; huella recuperada del PCB. | EGSE.kicad_sch + EGSE.kicad_pcb
59 | J25 | 1 | SHF-105-01-L-D-TH | SAMTEC | SHF-105-01-L-D-TH | SHF10501LDTH | THT | DOCUMENTADO | MPN documentado en el proyecto; huella recuperada del PCB. | EGSE.kicad_sch + EGSE.kicad_pcb
60 | J26 | 1 | TLW-110-05-T-S | SAMTEC | TLW-110-05-T-S | HDRV10W64P0X254 1X10 2540X248X838P; HDRV10W64P0X254_1X10_2540X248X838P | THT | DOCUMENTADO |  | EGSE.kicad_sch + EGSE.kicad_pcb
61 | J27 | 1 | Conn_01x08_MountingPin | Molex | 53398-0871 | 53398-0871 1x08-1MP P1.25mm Vertical; Molex_PicoBlade_53398-0871_1x08-1MP_P1.25mm_Vertical | SMD | DOCUMENTADO | MPN deducido de la huella. Confirmar número de contactos y montaje. | EGSE.kicad_sch + EGSE.kicad_pcb https://www.molex.com/en-us/products/part-detail/533980871
62 | J28 | 1 | Conn_01x08_MountingPin | Molex | 53398-0871 | 53398-0871 1x08-1MP P1.25mm Vertical; Molex_PicoBlade_53398-0871_1x08-1MP_P1.25mm_Vertical | SMD | DOCUMENTADO | MPN deducido de la huella. Confirmar número de contactos y montaje. | EGSE.kicad_sch + EGSE.kicad_pcb https://www.molex.com/en-us/products/part-detail/533980871
63 | J29 | 1 | CES-110-02-L-S | Samtec | CES-110-02-L-S | PinSocket 1x10 P2.54mm Vertical; PinSocket_1x10_P2.54mm_Vertical | THT | DOCUMENTADO | MPN documentado en el proyecto; huella recuperada del PCB. | EGSE.kicad_sch + EGSE.kicad_pcb
64 | J30 | 1 | CES-110-02-L-S | Samtec | CES-110-02-L-S | PinSocket 1x10 P2.54mm Vertical; PinSocket_1x10_P2.54mm_Vertical | THT | DOCUMENTADO | MPN documentado en el proyecto; huella recuperada del PCB. | EGSE.kicad_sch + EGSE.kicad_pcb
65 | J31 | 1 | CES-110-02-L-S | Samtec | CES-110-02-L-S | PinSocket 1x10 P2.54mm Vertical; PinSocket_1x10_P2.54mm_Vertical | THT | DOCUMENTADO | MPN documentado en el proyecto; huella recuperada del PCB. | EGSE.kicad_sch + EGSE.kicad_pcb
66 | J32 | 1 | CES-110-02-L-S | Samtec | CES-110-02-L-S | PinSocket 1x10 P2.54mm Vertical; PinSocket_1x10_P2.54mm_Vertical | THT | DOCUMENTADO | MPN documentado en el proyecto; huella recuperada del PCB. | EGSE.kicad_sch + EGSE.kicad_pcb
67 | J33 | 1 | CES-110-02-L-S | Samtec | CES-110-02-L-S | PinSocket 1x10 P2.54mm Vertical; PinSocket_1x10_P2.54mm_Vertical | THT | DOCUMENTADO | MPN documentado en el proyecto; huella recuperada del PCB. | EGSE.kicad_sch + EGSE.kicad_pcb
68 | J34 | 1 | Conn_01x11_MountingPin | Molex | 53261-1071 | 53261-1071 1x10-1MP P1.25mm Horizontal; Molex_PicoBlade_53261-1071_1x10-1MP_P1.25mm_Horizontal | SMD | DOCUMENTADO | MPN deducido de la huella. Confirmar número de contactos y montaje. | EGSE.kicad_sch + EGSE.kicad_pcb https://www.molex.com/en-us/products/part-detail/532611071
69 | J35 | 1 | Conn_01x11_MountingPin | Molex | 53261-1071 | 53261-1071 1x10-1MP P1.25mm Horizontal; Molex_PicoBlade_53261-1071_1x10-1MP_P1.25mm_Horizontal | SMD | DOCUMENTADO | MPN deducido de la huella. Confirmar número de contactos y montaje. | EGSE.kicad_sch + EGSE.kicad_pcb https://www.molex.com/en-us/products/part-detail/532611071
70 | J36 | 1 | Conn_01x11_MountingPin | Molex | 53261-1071 | 53261-1071 1x10-1MP P1.25mm Horizontal; Molex_PicoBlade_53261-1071_1x10-1MP_P1.25mm_Horizontal | SMD | DOCUMENTADO | MPN deducido de la huella. Confirmar número de contactos y montaje. | EGSE.kicad_sch + EGSE.kicad_pcb https://www.molex.com/en-us/products/part-detail/532611071
71 | J37 | 1 | Conn_01x11_MountingPin | Molex | 53261-1071 | 53261-1071 1x10-1MP P1.25mm Horizontal; Molex_PicoBlade_53261-1071_1x10-1MP_P1.25mm_Horizontal | SMD | DOCUMENTADO | MPN deducido de la huella. Confirmar número de contactos y montaje. | EGSE.kicad_sch + EGSE.kicad_pcb https://www.molex.com/en-us/products/part-detail/532611071
72 | J38 | 1 | Conn_01x11_MountingPin | Molex | 53261-0971 | 53261-0971 1x09-1MP P1.25mm Horizontal; Molex_PicoBlade_53261-0971_1x09-1MP_P1.25mm_Horizontal | SMD | DOCUMENTADO | MPN deducido de la huella. Confirmar número de contactos y montaje. | EGSE.kicad_sch + EGSE.kicad_pcb https://www.molex.com/en-us/products/part-detail/532610971
73 | J39 | 1 | 53261-1471 | MOLEX | 53261-1471 | 53261-1571 1x15-1MP P1.25mm Horizontal; Molex_PicoBlade_53261-1571_1x15-1MP_P1.25mm_Horizontal | SMD | DOCUMENTADO |  | EGSE.kicad_sch + EGSE.kicad_pcb
74 | J40 | 1 | 53261-0271 | MOLEX | 53261-0271 | 53261-0271 1x02-1MP P1.25mm Horizontal; Molex_PicoBlade_53261-0271_1x02-1MP_P1.25mm_Horizontal | SMD | DOCUMENTADO | MPN documentado en el proyecto; huella recuperada del PCB. | EGSE.kicad_sch + EGSE.kicad_pcb
75 | J41 | 1 | Pico-Clasp_01x03 | Molex | 203556-0307 | Pico-Clasp, paso 1.00 mm; huella Picoclasp03; Picoclasp03 | SMD | DOCUMENTADO | MPN documentado en el proyecto; huella recuperada del PCB. | EGSE.kicad_sch + EGSE.kicad_pcb
76 | J42 | 1 | TLW-108-05-T-S | SAMTEC | TLW-108-05-T-S | SAMTEC TLW-108-05-T-S; SAMTEC_TLW-108-05-T-S | THT | DOCUMENTADO | MPN documentado en el proyecto; huella recuperada del PCB. | EGSE.kicad_sch + EGSE.kicad_pcb
77 | J43 | 1 | HTSW-110-07-G-S | SAMTEC | HTSW-110-07-G-S | HDRV10W64P0X254 1X10 2540X248X838P; HDRV10W64P0X254_1X10_2540X248X838P | THT | DOCUMENTADO | MPN documentado en el proyecto; huella recuperada del PCB. | EGSE.kicad_sch + EGSE.kicad_pcb
78 | J44 | 1 | HTSW-110-07-G-S | SAMTEC | HTSW-110-07-G-S | HDRV10W64P0X254 1X10 2540X248X838P; HDRV10W64P0X254_1X10_2540X248X838P | THT | DOCUMENTADO | MPN documentado en el proyecto; huella recuperada del PCB. | EGSE.kicad_sch + EGSE.kicad_pcb
79 | J45 | 1 | HTSW-110-07-G-S | SAMTEC | HTSW-110-07-G-S | HDRV10W64P0X254 1X10 2540X248X838P; HDRV10W64P0X254_1X10_2540X248X838P | THT | DOCUMENTADO | MPN documentado en el proyecto; huella recuperada del PCB. | EGSE.kicad_sch + EGSE.kicad_pcb
80 | J46 | 1 | Conn_01x11_MountingPin | Molex | 53261-1071 | 53261-1071 1x10-1MP P1.25mm Horizontal; Molex_PicoBlade_53261-1071_1x10-1MP_P1.25mm_Horizontal | SMD | DOCUMENTADO | MPN deducido de la huella. Confirmar número de contactos y montaje. | EGSE.kicad_sch + EGSE.kicad_pcb https://www.molex.com/en-us/products/part-detail/532611071
81 | J47 | 1 | Conn_01x11_MountingPin | Molex | 53261-1071 | 53261-1071 1x10-1MP P1.25mm Horizontal; Molex_PicoBlade_53261-1071_1x10-1MP_P1.25mm_Horizontal | SMD | DOCUMENTADO | MPN deducido de la huella. Confirmar número de contactos y montaje. | EGSE.kicad_sch + EGSE.kicad_pcb https://www.molex.com/en-us/products/part-detail/532611071
82 | J48 | 1 | Conn_01x11_MountingPin | Molex | 53261-1071 | 53261-1071 1x10-1MP P1.25mm Horizontal; Molex_PicoBlade_53261-1071_1x10-1MP_P1.25mm_Horizontal | SMD | DOCUMENTADO | MPN deducido de la huella. Confirmar número de contactos y montaje. | EGSE.kicad_sch + EGSE.kicad_pcb https://www.molex.com/en-us/products/part-detail/532611071
83 | J49 | 1 | Conn_01x11_MountingPin | Molex | 53261-1071 | 53261-1071 1x10-1MP P1.25mm Horizontal; Molex_PicoBlade_53261-1071_1x10-1MP_P1.25mm_Horizontal | SMD | DOCUMENTADO | MPN deducido de la huella. Confirmar número de contactos y montaje. | EGSE.kicad_sch + EGSE.kicad_pcb https://www.molex.com/en-us/products/part-detail/532611071
84 | J50 | 1 | Conn_01x11_MountingPin | Molex | 53261-0971 | 53261-0971 1x09-1MP P1.25mm Horizontal; Molex_PicoBlade_53261-0971_1x09-1MP_P1.25mm_Horizontal | SMD | DOCUMENTADO | MPN deducido de la huella. Confirmar número de contactos y montaje. | EGSE.kicad_sch + EGSE.kicad_pcb https://www.molex.com/en-us/products/part-detail/532610971
85 | J51 | 1 | 53261-1471 | MOLEX | 53261-1471 | 53261-1571 1x15-1MP P1.25mm Horizontal; Molex_PicoBlade_53261-1571_1x15-1MP_P1.25mm_Horizontal | SMD | DOCUMENTADO |  | EGSE.kicad_sch + EGSE.kicad_pcb
86 | J52 | 1 | Pico-Clasp_01x03 | Molex | 203556-0307 | Pico-Clasp, paso 1.00 mm; huella Picoclasp03; Picoclasp03 | SMD | DOCUMENTADO | MPN documentado en el proyecto; huella recuperada del PCB. | EGSE.kicad_sch + EGSE.kicad_pcb
87 | J53 | 1 | 53261-0271 | MOLEX | 53261-0271 | 53261-0271 1x02-1MP P1.25mm Horizontal; Molex_PicoBlade_53261-0271_1x02-1MP_P1.25mm_Horizontal | SMD | DOCUMENTADO | MPN documentado en el proyecto; huella recuperada del PCB. | EGSE.kicad_sch + EGSE.kicad_pcb
88 | J54 | 1 | 73099-2 | Pomona Electronics | 73099-2 | Banana 4 mm, PCB horizontal, THT; 73099-2 | THT | DOCUMENTADO |  | EGSE.kicad_sch + EGSE.kicad_pcb https://www.pomonaelectronics.com/files/datasheets/d73099_101.pdf
89 | J55 | 1 | 73099-0 | Pomona Electronics | 73099-0 | Banana 4 mm, PCB horizontal, THT; 73099-2 | THT | DOCUMENTADO |  | EGSE.kicad_sch + EGSE.kicad_pcb https://www.pomonaelectronics.com/files/datasheets/d73099_101.pdf
90 | J56 | 1 | CES-102-02-L-S | Samtec | CES-102-02-L-S | Socket 1x2, paso 2.54 mm; CES-102-02 | THT | DOCUMENTADO | MPN documentado en el proyecto; huella recuperada del PCB. | EGSE.kicad_sch + EGSE.kicad_pcb
91 | J57 | 1 | CES-102-02-L-S | Samtec | CES-102-02-L-S | Socket 1x2, paso 2.54 mm; CES-102-02 | THT | DOCUMENTADO | MPN documentado en el proyecto; huella recuperada del PCB. | EGSE.kicad_sch + EGSE.kicad_pcb
92 | J58 | 1 | SSQ-120-01-L-D | SAMTEC | SSQ-120-01-L-D | SSQ-120-XX-YYY-D | THT | DOCUMENTADO | MPN documentado en el proyecto; huella recuperada del PCB. | EGSE.kicad_sch + EGSE.kicad_pcb
93 | J59 | 1 | CES-110-02-L-S | Samtec | CES-110-02-L-S | PinSocket 1x10 P2.54mm Vertical; PinSocket_1x10_P2.54mm_Vertical | THT | DOCUMENTADO | MPN documentado en el proyecto; huella recuperada del PCB. | EGSE.kicad_sch + EGSE.kicad_pcb
94 | J60 | 1 | CES-110-02-L-S | Samtec | CES-110-02-L-S | PinSocket 1x10 P2.54mm Vertical; PinSocket_1x10_P2.54mm_Vertical | THT | DOCUMENTADO | MPN documentado en el proyecto; huella recuperada del PCB. | EGSE.kicad_sch + EGSE.kicad_pcb
95 | J61 | 1 | CES-110-02-L-S | Samtec | CES-110-02-L-S | PinSocket 1x10 P2.54mm Vertical; PinSocket_1x10_P2.54mm_Vertical | THT | DOCUMENTADO | MPN documentado en el proyecto; huella recuperada del PCB. | EGSE.kicad_sch + EGSE.kicad_pcb
96 | J62 | 1 | 68001-109HLF | Amphenol Communications Solutions | 68001-109HLF | HDRV9W90P0X254 1X9 2286X241X1143P; HDRV9W90P0X254_1X9_2286X241X1143P | THT | DOCUMENTADO | MPN documentado en el proyecto; huella recuperada del PCB. | EGSE.kicad_sch + EGSE.kicad_pcb
97 | J63 | 1 | 22-28-4153 | Molex | 22-28-4153 | HDRV15W66P0X254 1X15 3810X249X838P; HDRV15W66P0X254_1X15_3810X249X838P | THT | DOCUMENTADO | MPN documentado en el proyecto; huella recuperada del PCB. | EGSE.kicad_sch + EGSE.kicad_pcb
98 | J64 | 1 | 87224-2 | TE Connectivity | 87224-2 | 872242 | THT | DOCUMENTADO | MPN documentado en el proyecto; huella recuperada del PCB. | EGSE.kicad_sch + EGSE.kicad_pcb
99 | J65 | 1 | 54101-S0803LF | Amphenol Communications Solutions | 54101-S0803LF | 54101S0803LF | THT | DOCUMENTADO | MPN documentado en el proyecto; huella recuperada del PCB. | EGSE.kicad_sch + EGSE.kicad_pcb
100 | J66 | 1 | 87224-2 | TE Connectivity | 87224-2 | 872242 | THT | DOCUMENTADO | MPN documentado en el proyecto; huella recuperada del PCB. | EGSE.kicad_sch + EGSE.kicad_pcb
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

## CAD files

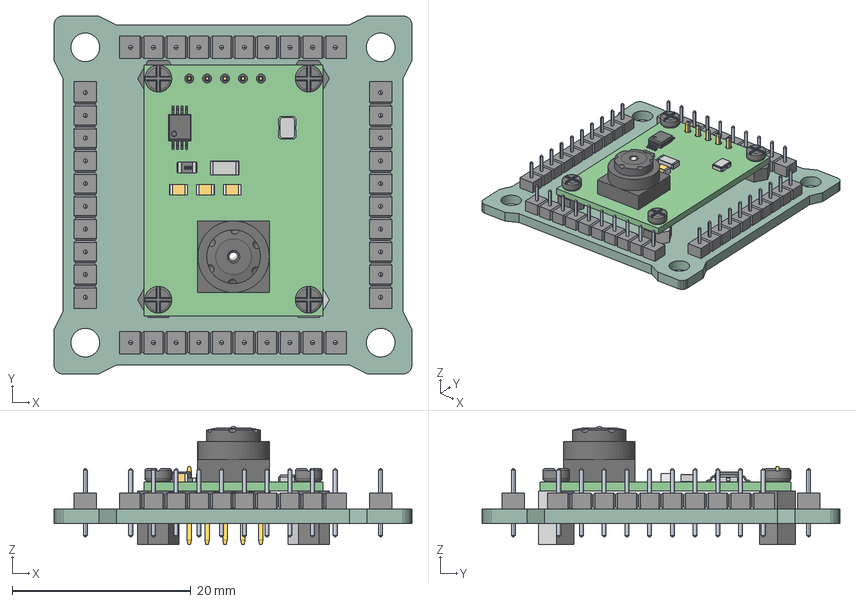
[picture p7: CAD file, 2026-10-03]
01_Hardware/pocat-hw-main/Otros Payloads/pq_pl1/PQ_PL1/PQ_PL1.step
40.0 x 40.0 x 13.2 mm
PCB

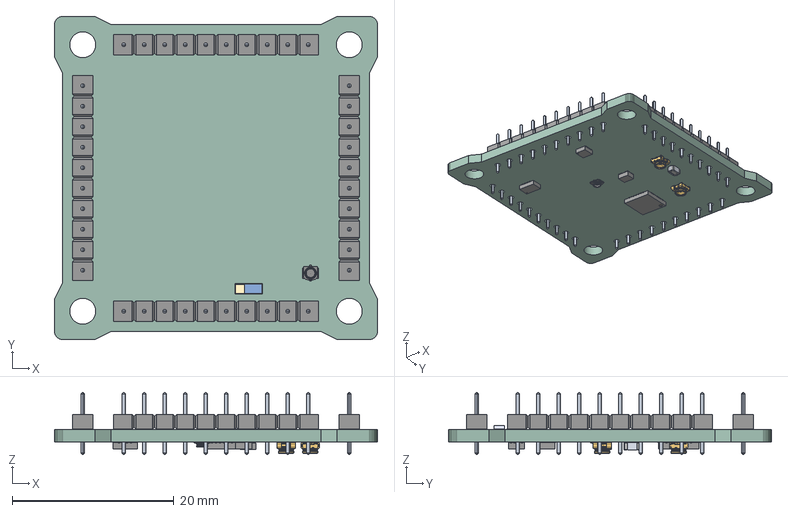
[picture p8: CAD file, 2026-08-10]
01_Hardware/pocat-hw-main/Otros Payloads/pq_pl2/PQ_PL2/PQ_PL2.step
40.0 x 40.0 x 7.70 mm
PCB

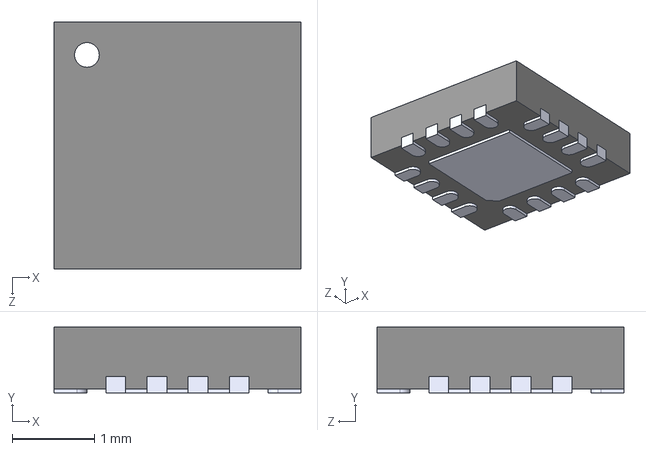
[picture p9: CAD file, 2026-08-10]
01_Hardware/pocat-hw-main/PQ_ADCS_HBridge/DRV8214RTER/DRV8214RTER.step
3.00 x 0.8 x 3.00 mm

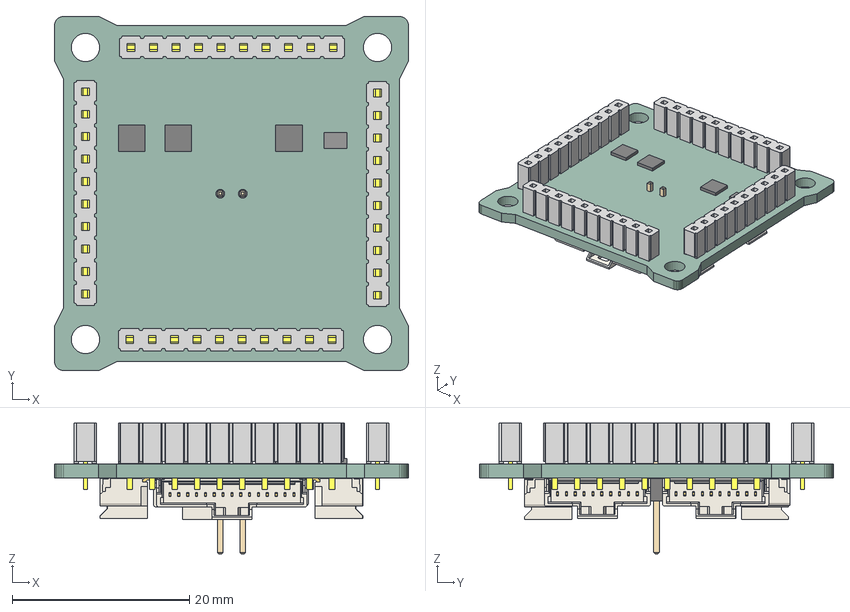
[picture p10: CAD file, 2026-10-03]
01_Hardware/pocat-hw-main/PQ_ADCS_HBridge/PQ_ADCS.step
40.0 x 40.0 x 14.8 mm
PCB

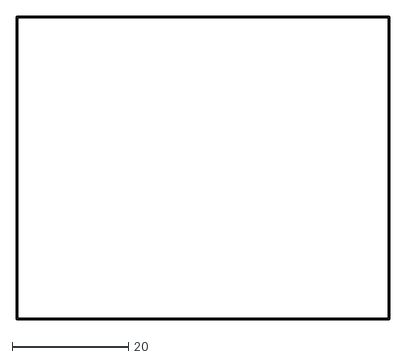
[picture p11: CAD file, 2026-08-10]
01_Hardware/pocat-hw-main/pq_botboard/PQ_BotBoard/PQ_BotBoard-Edge_Cuts.dxf
64.3 x 52.3

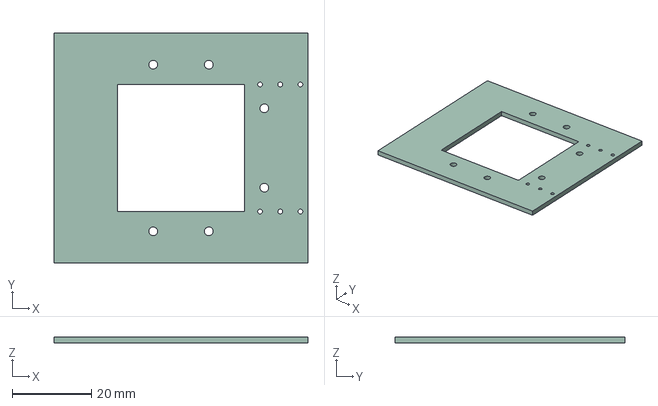
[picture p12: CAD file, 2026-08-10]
01_Hardware/pocat-hw-main/pq_botnotsobot/PQ_Botnotsobot/PQ_Botnotsobot.step
64.0 x 58.0 x 1.58 mm

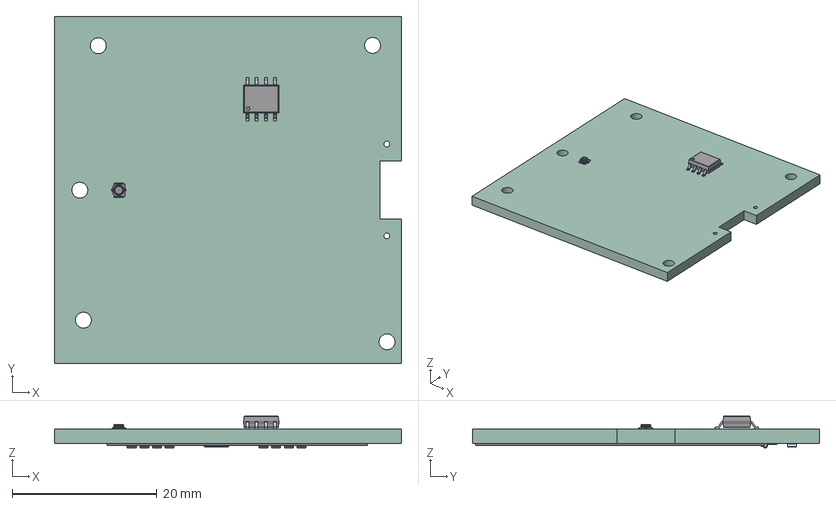
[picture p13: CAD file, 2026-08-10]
01_Hardware/pocat-hw-main/pq_latboard/PQ_Lat_Board/PQ_Lat_Board.step
48.0 x 48.0 x 4.39 mm
PCB

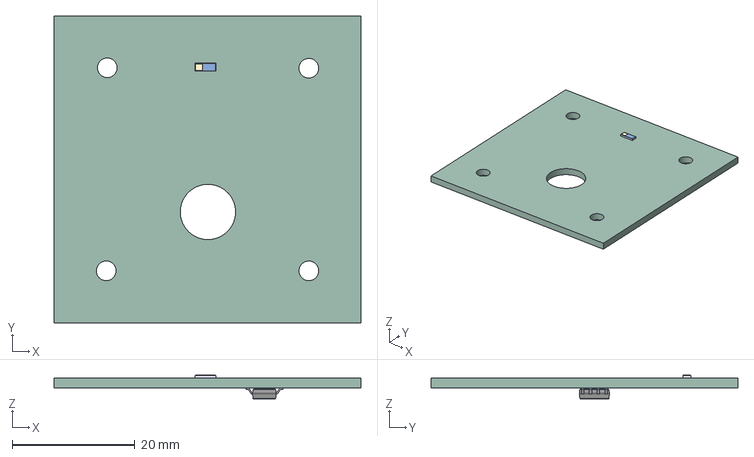
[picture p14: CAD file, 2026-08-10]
01_Hardware/pocat-hw-main/pq_topboard/PQ1_TopBoard/PQ1_TopBoard.step
50.0 x 50.0 x 3.87 mm
PCB

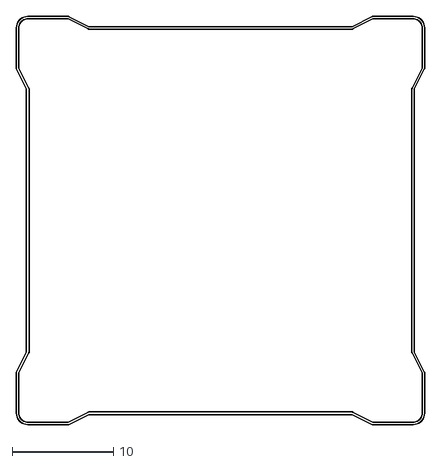
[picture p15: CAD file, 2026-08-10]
04_CAD/assembly/adcs/PQ_ADCS-Edge_Cuts.dxf
40.3 x 40.3

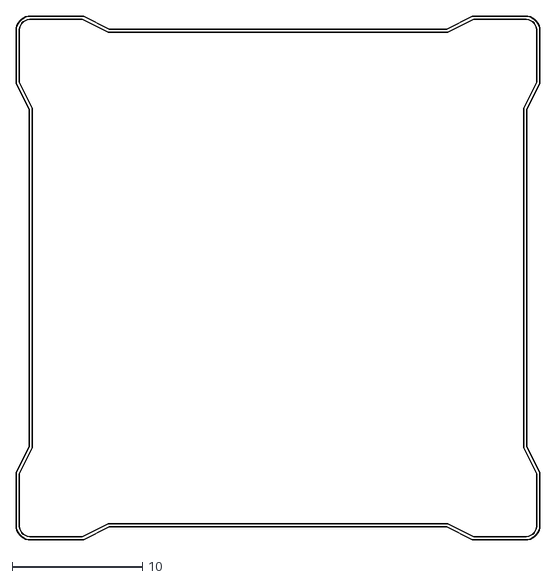
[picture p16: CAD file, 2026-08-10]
04_CAD/assembly/eps/eps-board/PQ_EPS-Edge_Cuts.dxf
40.2 x 40.2

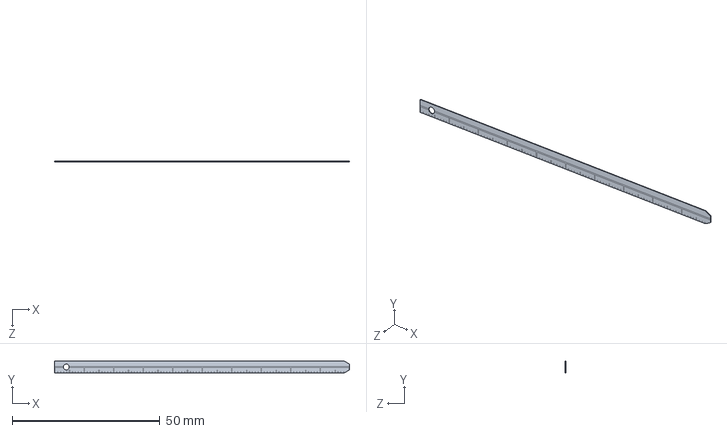
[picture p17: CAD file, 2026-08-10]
04_CAD/assembly/lateral/antenna/Antenna_Tape.SLDPRT
100.0 x 4.00 x 0.2 mm

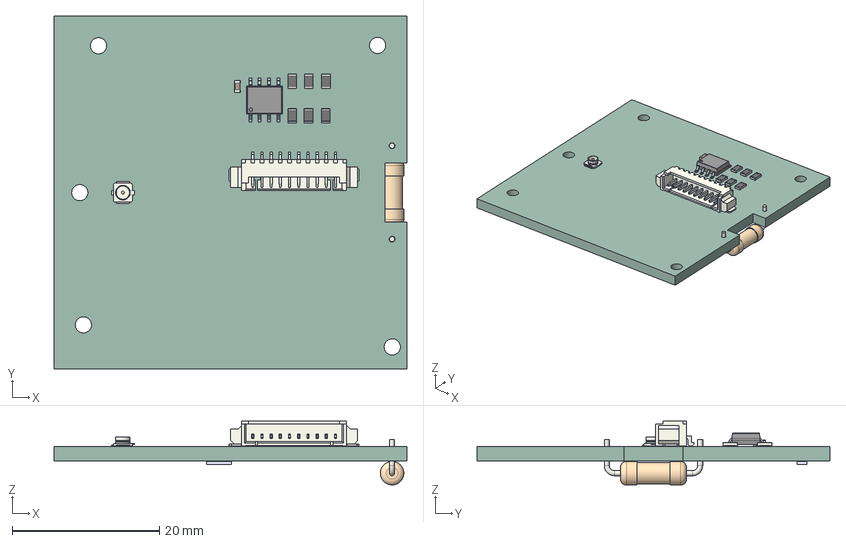
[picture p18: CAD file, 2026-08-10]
04_CAD/assembly/lateral/lateral-board/PQ_Lat_Board.step
48.0 x 48.0 x 8.70 mm
R_0805_2012Metric x 6
Molex_53261_1071
ASSEMBLY
C_0603_1608Metric
U.FL_Hirose_U.FL-R-SMT-1_Vertical
SLCD-61N8
R_Axial_DIN0309_L90mm_D32mm_P1270mm_Horizontal
PQ_Lat_Board PCB

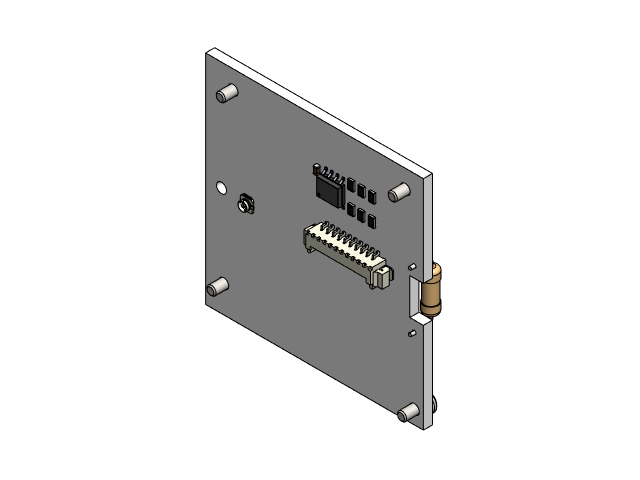
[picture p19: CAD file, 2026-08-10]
04_CAD/assembly/lateral/pq-lateral-assembly.SLDASM
PQ_Lat_Board
BN 20146 3233654 hexalobular socket head cap screw M2x5 x 4
Solar_Cell_Azur

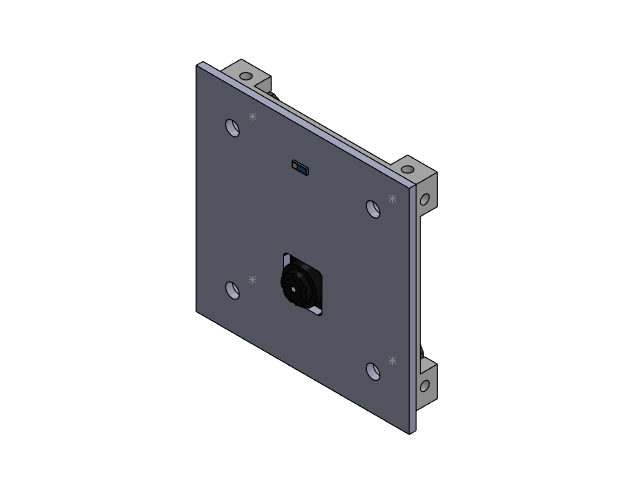
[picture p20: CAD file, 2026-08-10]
04_CAD/assembly/payloads/pl1/pl1.SLDASM
pq-pl1
Support_Top
PQ-STRUCTURE-M3_Spacer_Round x 4
pq-pl1-top

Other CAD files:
04_CAD/assembly/payloads/pl3/pl3.SLDASM
04_CAD/Vitrina_PQ/Vitrina_PQ_Assembly.SLDASM
04_CAD/assembly/eps/battery/Battery.SLDPRT
01_Hardware/pocat-hw-main/Otros Payloads/pq_pl1/PQ_PL1/PQ_PL1-B_Silkscreen.dxf
01_Hardware/pocat-hw-main/Otros Payloads/pq_pl1/PQ_PL1/PQ_PL1-Edge_Cuts.dxf
01_Hardware/pocat-hw-main/Otros Payloads/pq_pl1/PQ_PL1/PQ_PL1-F_Silkscreen.dxf
01_Hardware/pocat-hw-main/pq_botboard/PQ_BotBoard/PQ_BotBoard-F_Silkscreen.dxf
04_CAD/Vitrina_PQ/acrylic_laser_cutting_design.dxf
04_CAD/Vitrina_PQ/base.SLDPRT
04_CAD/Vitrina_PQ/metacrilat_curt.SLDPRT
04_CAD/Vitrina_PQ/metacrilat_llarg.SLDPRT
04_CAD/Vitrina_PQ/metacrilat_tapa.SLDPRT
04_CAD/assembly/MGSE_Assembly/hold_pinza.SLDPRT
04_CAD/assembly/MGSE_Assembly/support_VGA-top.SLDPRT
04_CAD/assembly/MGSE_Assembly/support_pq-bottom.SLDPRT
04_CAD/assembly/MGSE_Assembly/support_pq-bottom_2nStep.SLDPRT
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

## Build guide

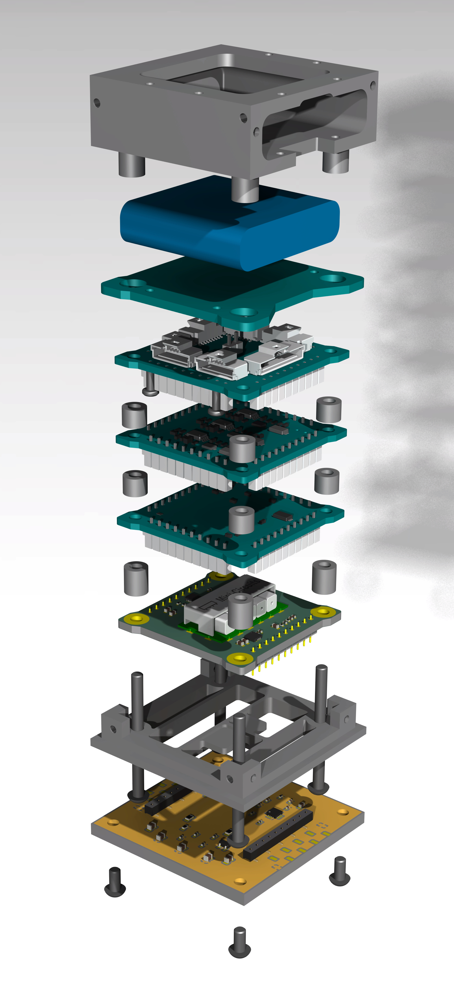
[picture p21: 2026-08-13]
04_CAD/assembly/assembly_v1/IMG_010.jpg

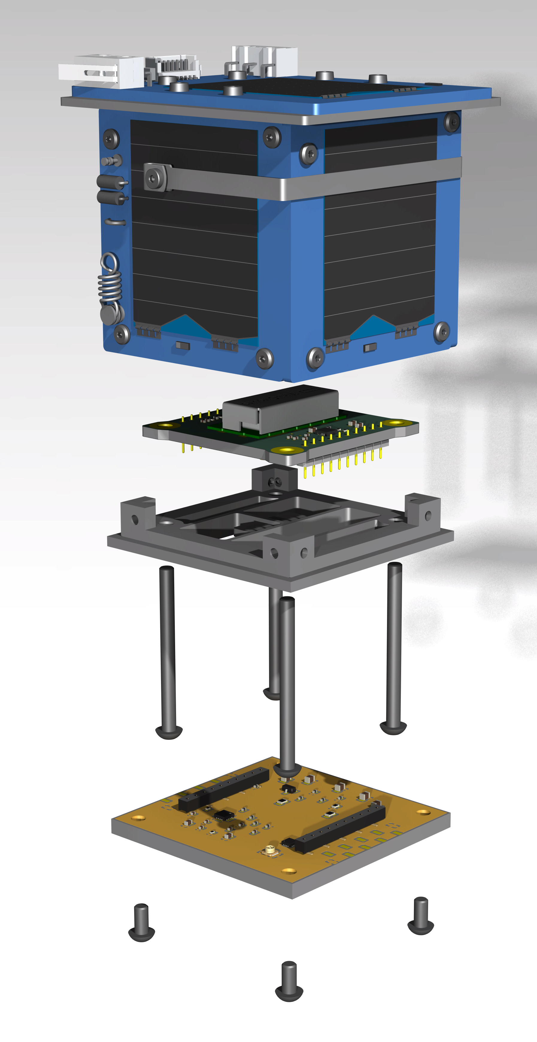
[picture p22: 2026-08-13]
04_CAD/assembly/assembly_v1/IMG_007.jpg

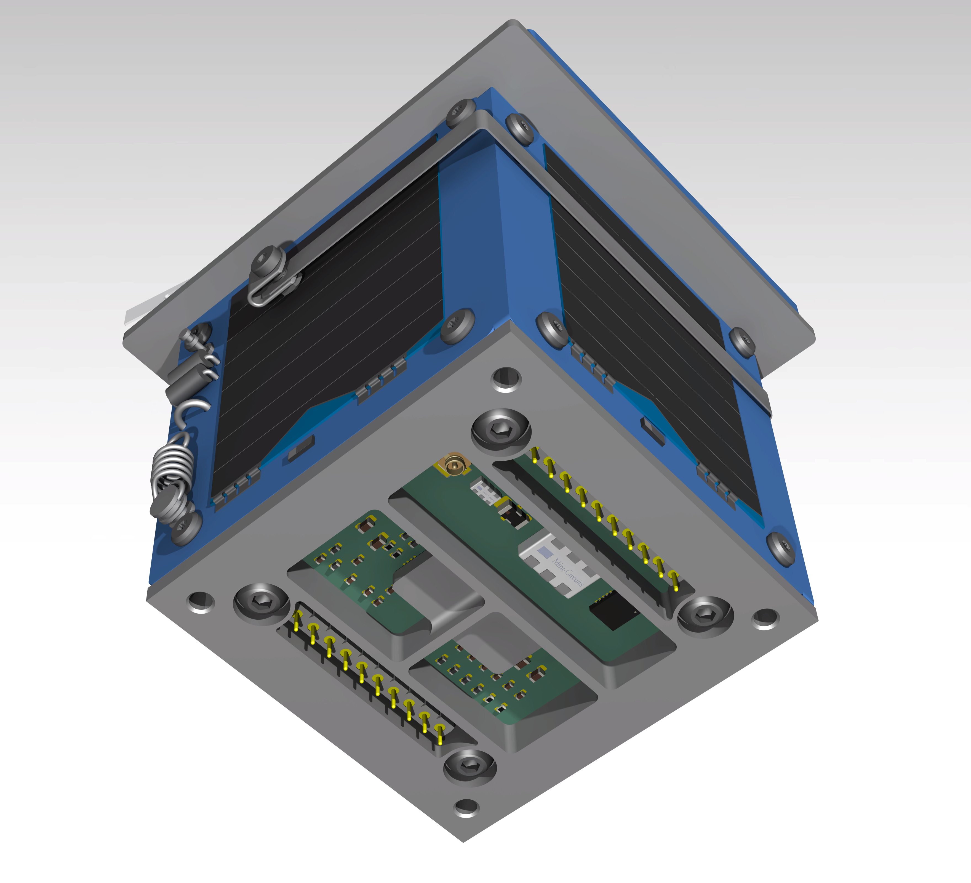
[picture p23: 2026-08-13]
04_CAD/assembly/assembly_v1/IMG_004.jpg

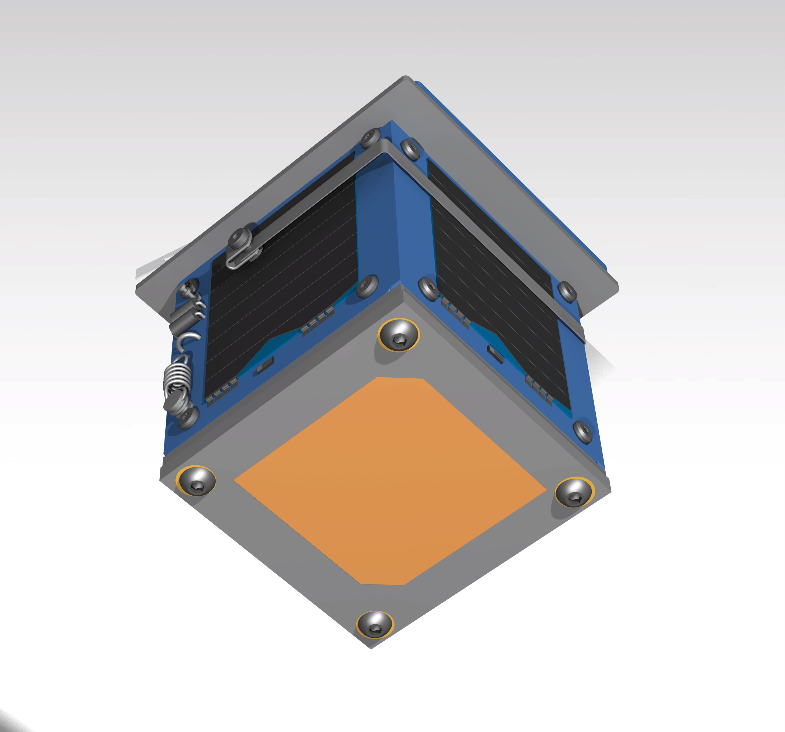
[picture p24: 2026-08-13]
04_CAD/assembly/assembly_v1/IMG_003.jpg

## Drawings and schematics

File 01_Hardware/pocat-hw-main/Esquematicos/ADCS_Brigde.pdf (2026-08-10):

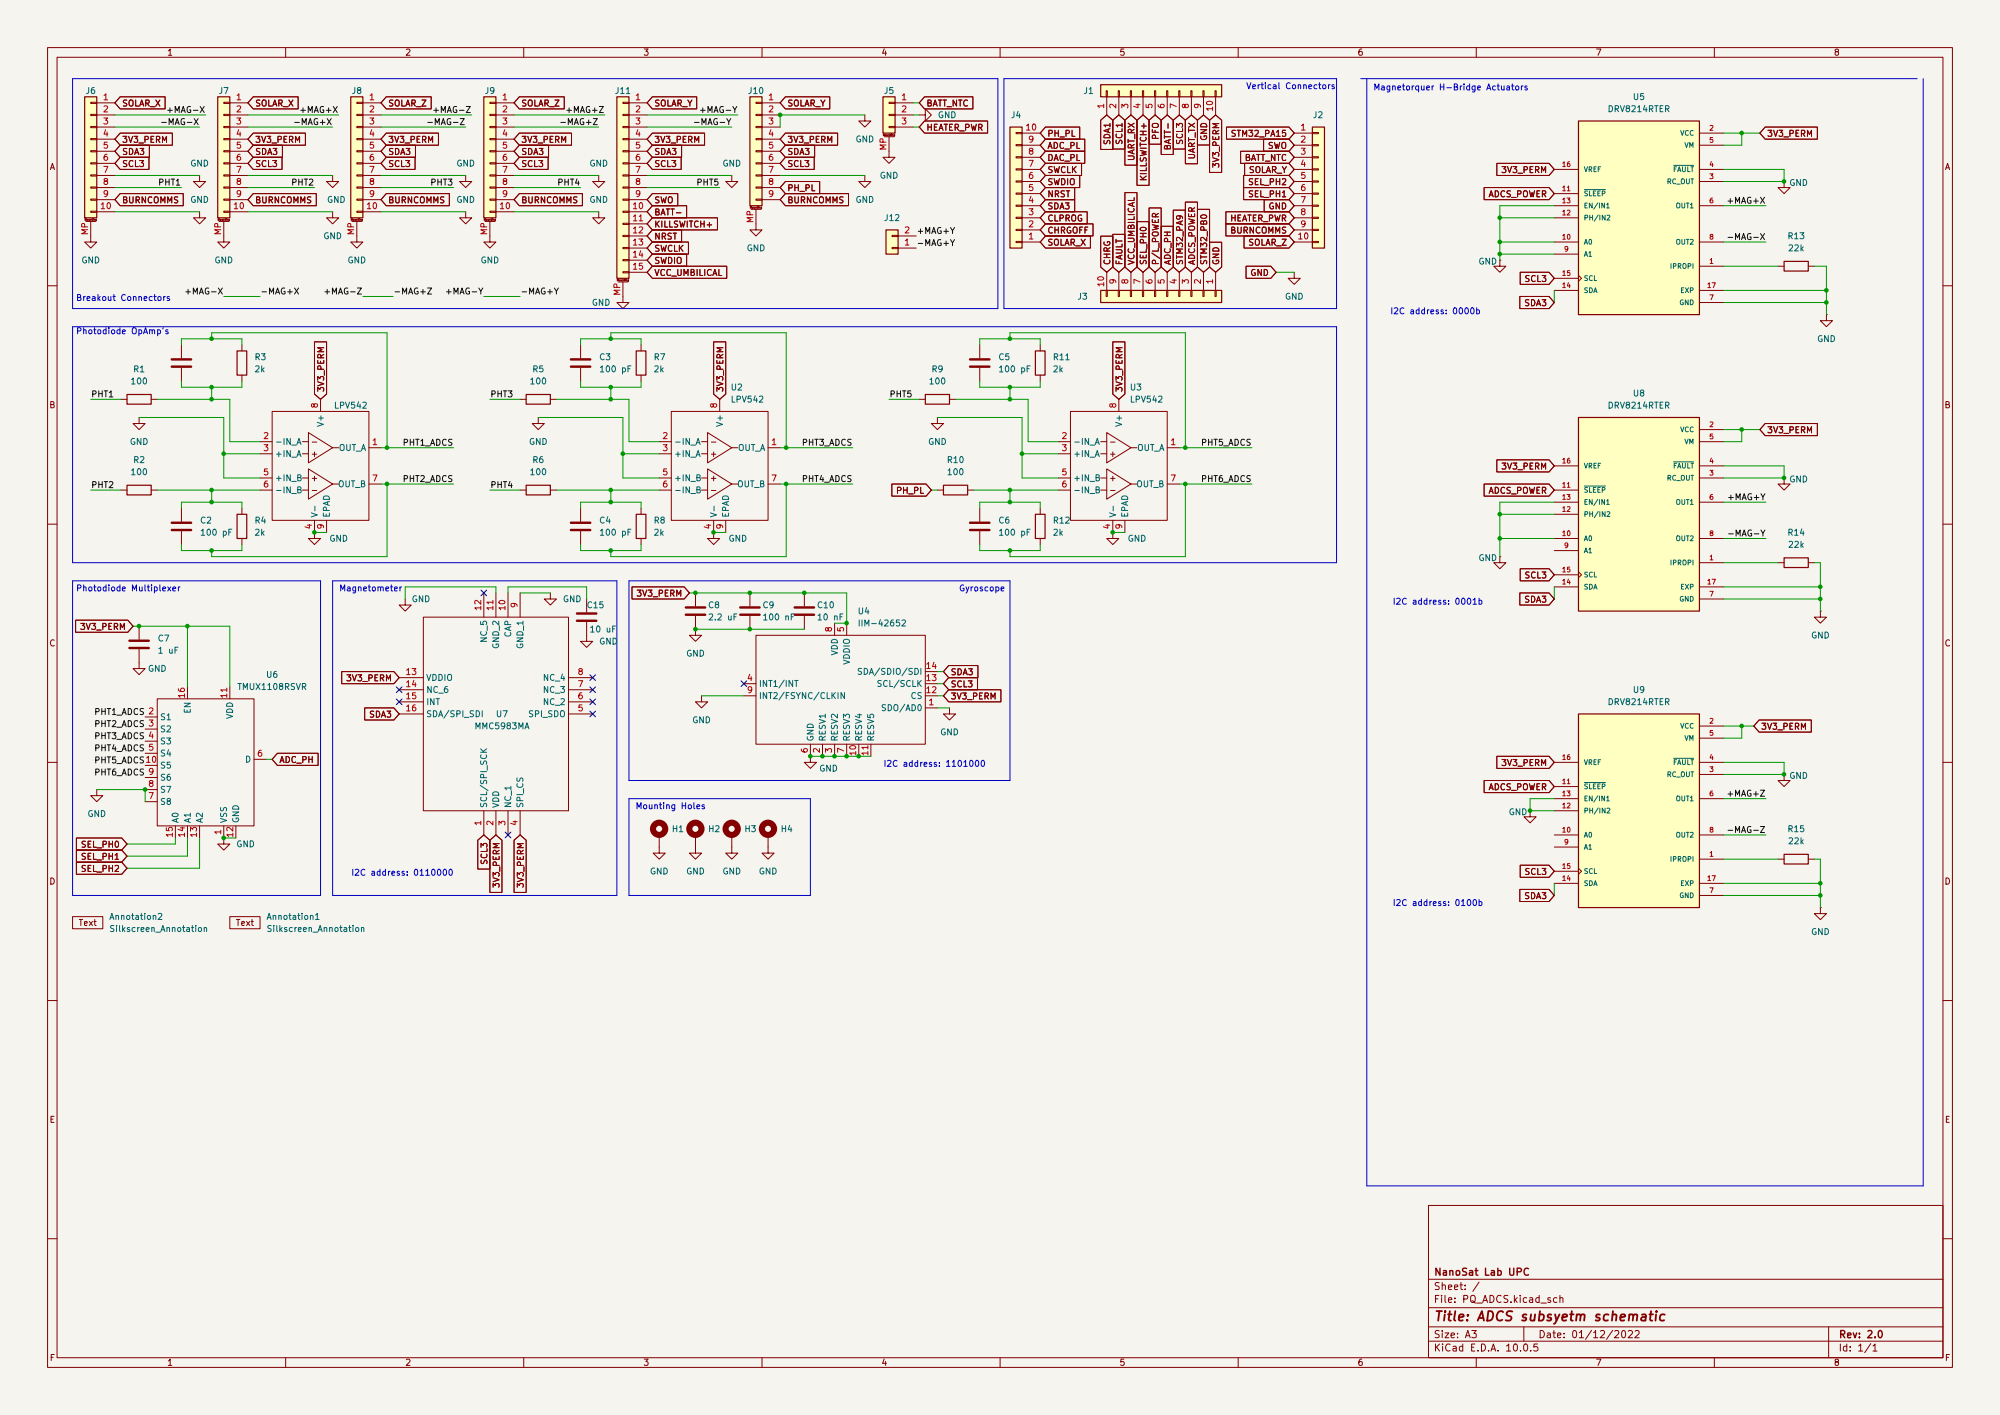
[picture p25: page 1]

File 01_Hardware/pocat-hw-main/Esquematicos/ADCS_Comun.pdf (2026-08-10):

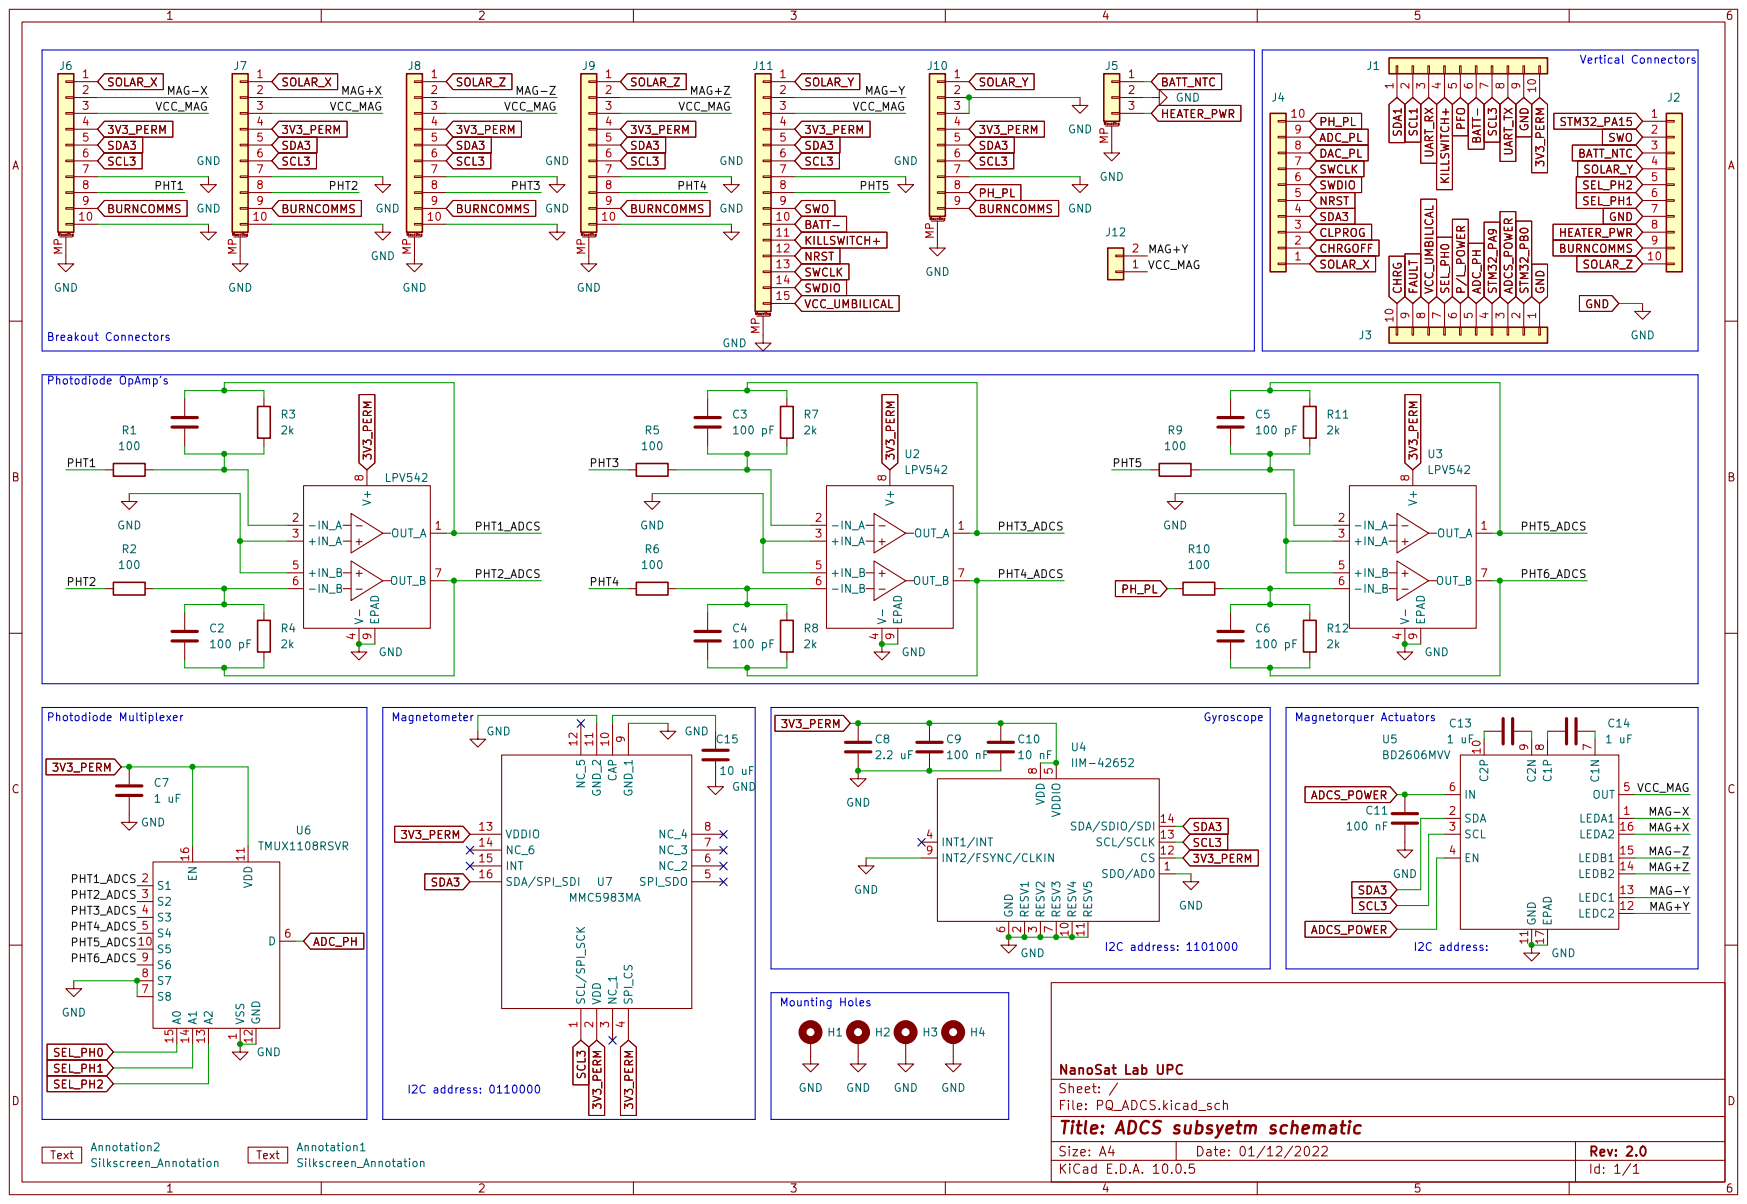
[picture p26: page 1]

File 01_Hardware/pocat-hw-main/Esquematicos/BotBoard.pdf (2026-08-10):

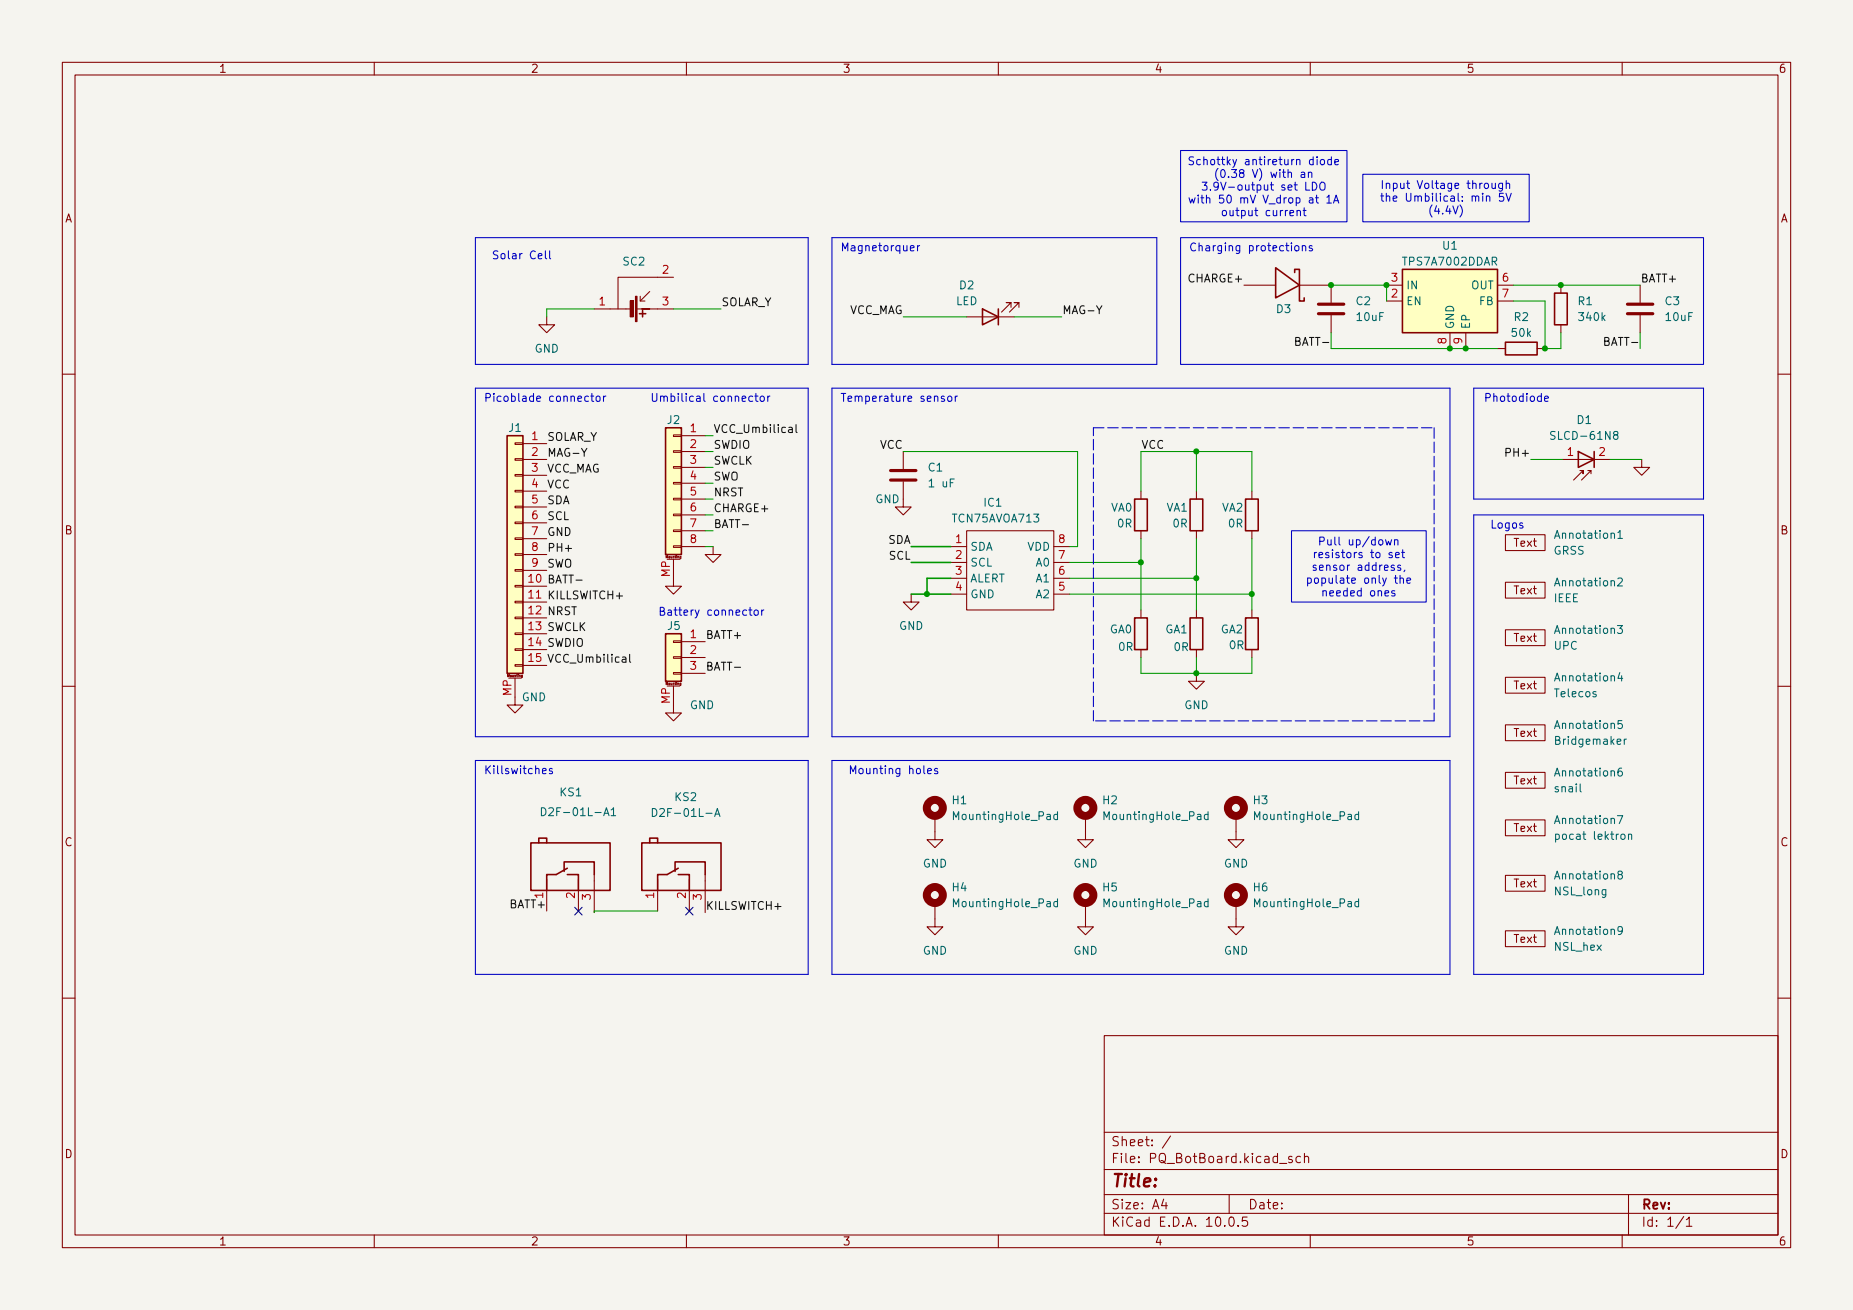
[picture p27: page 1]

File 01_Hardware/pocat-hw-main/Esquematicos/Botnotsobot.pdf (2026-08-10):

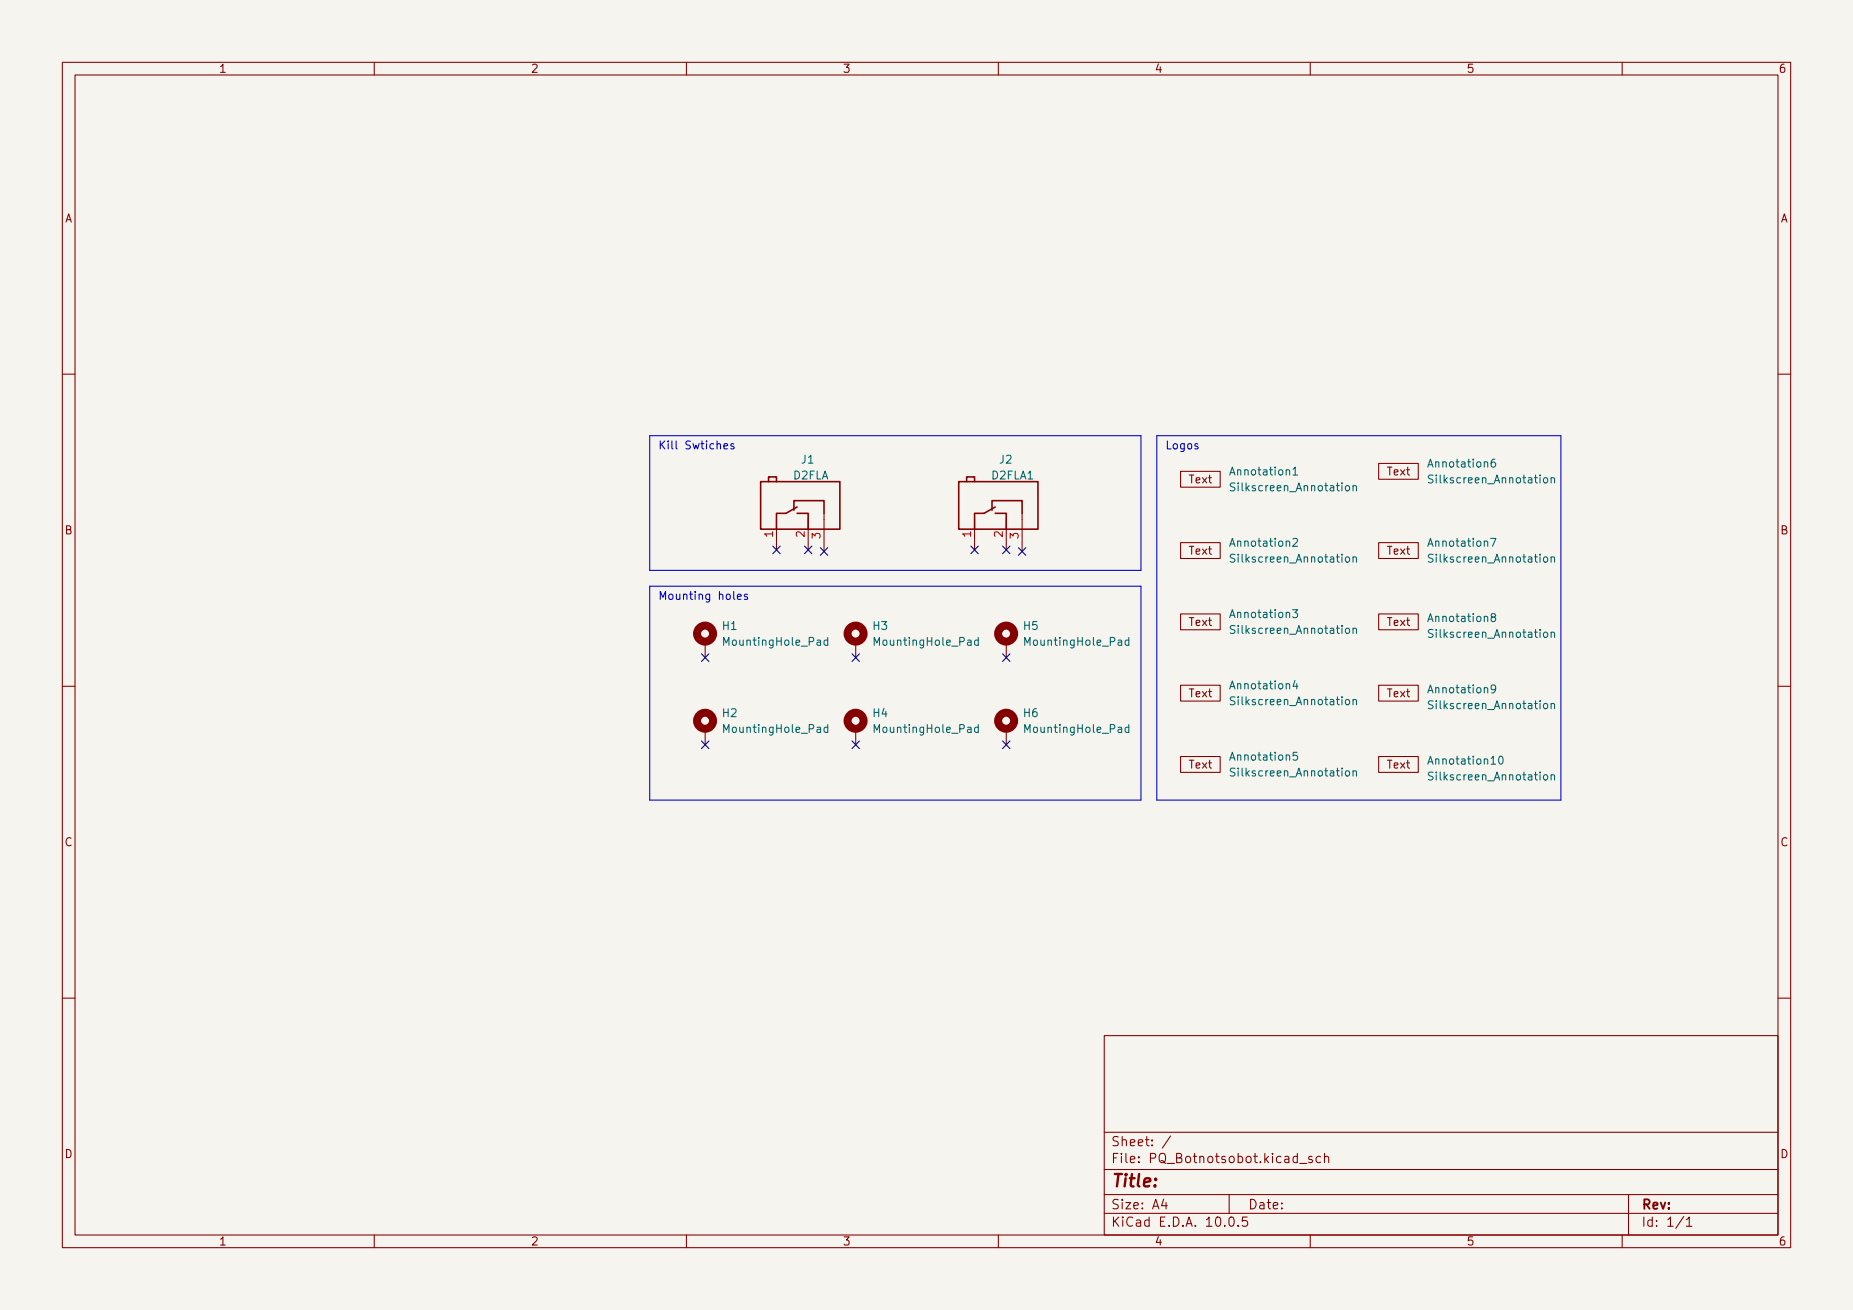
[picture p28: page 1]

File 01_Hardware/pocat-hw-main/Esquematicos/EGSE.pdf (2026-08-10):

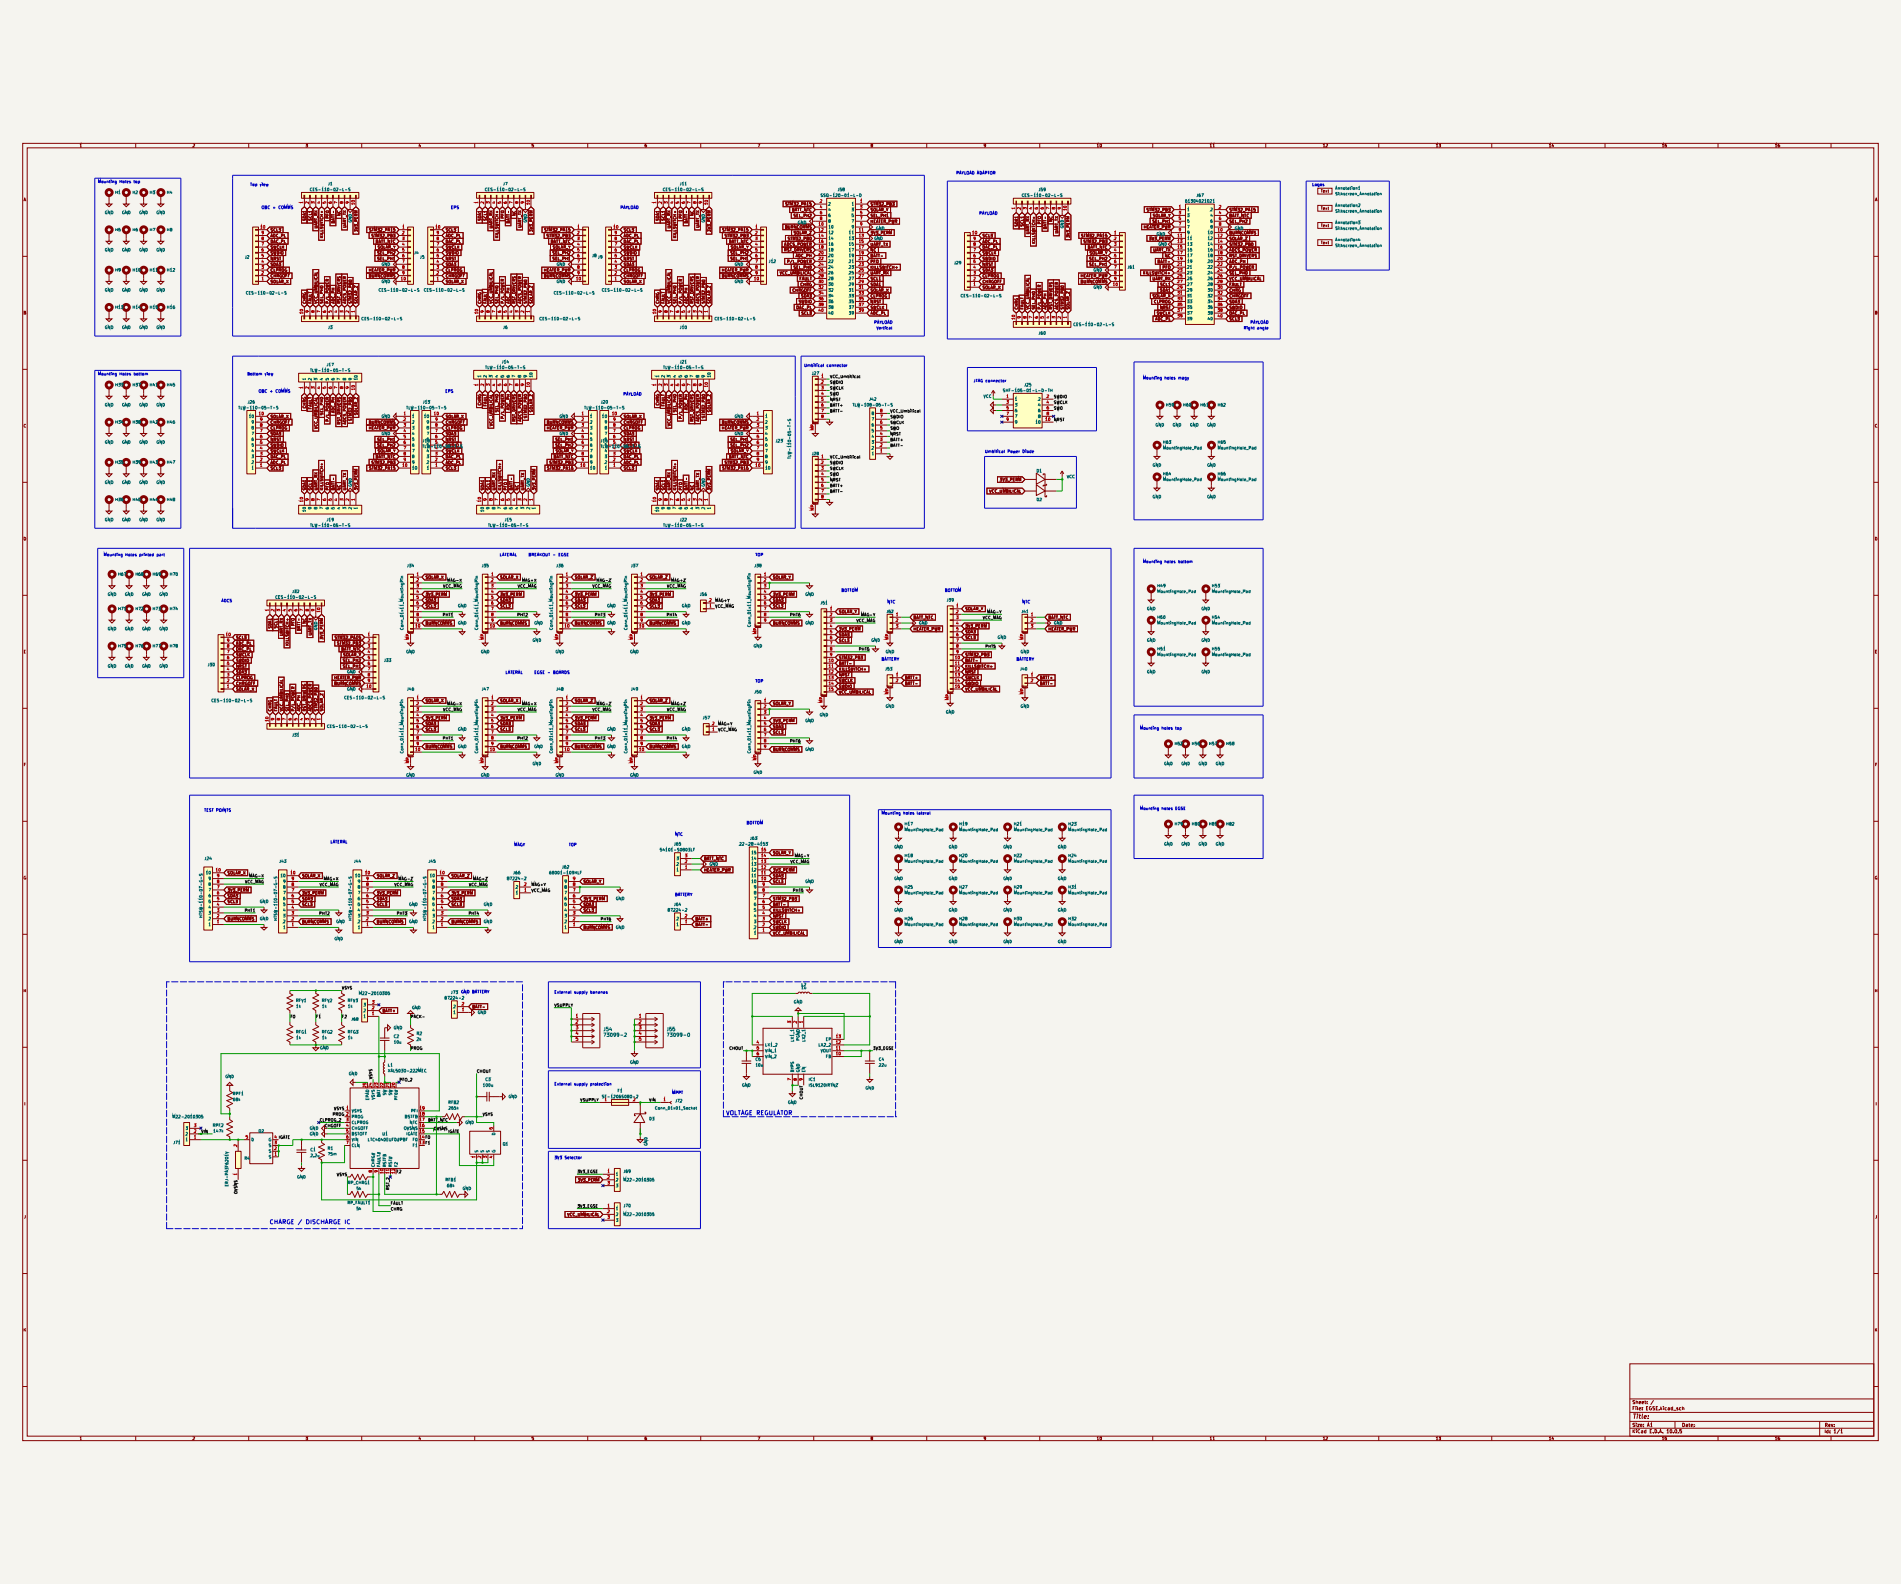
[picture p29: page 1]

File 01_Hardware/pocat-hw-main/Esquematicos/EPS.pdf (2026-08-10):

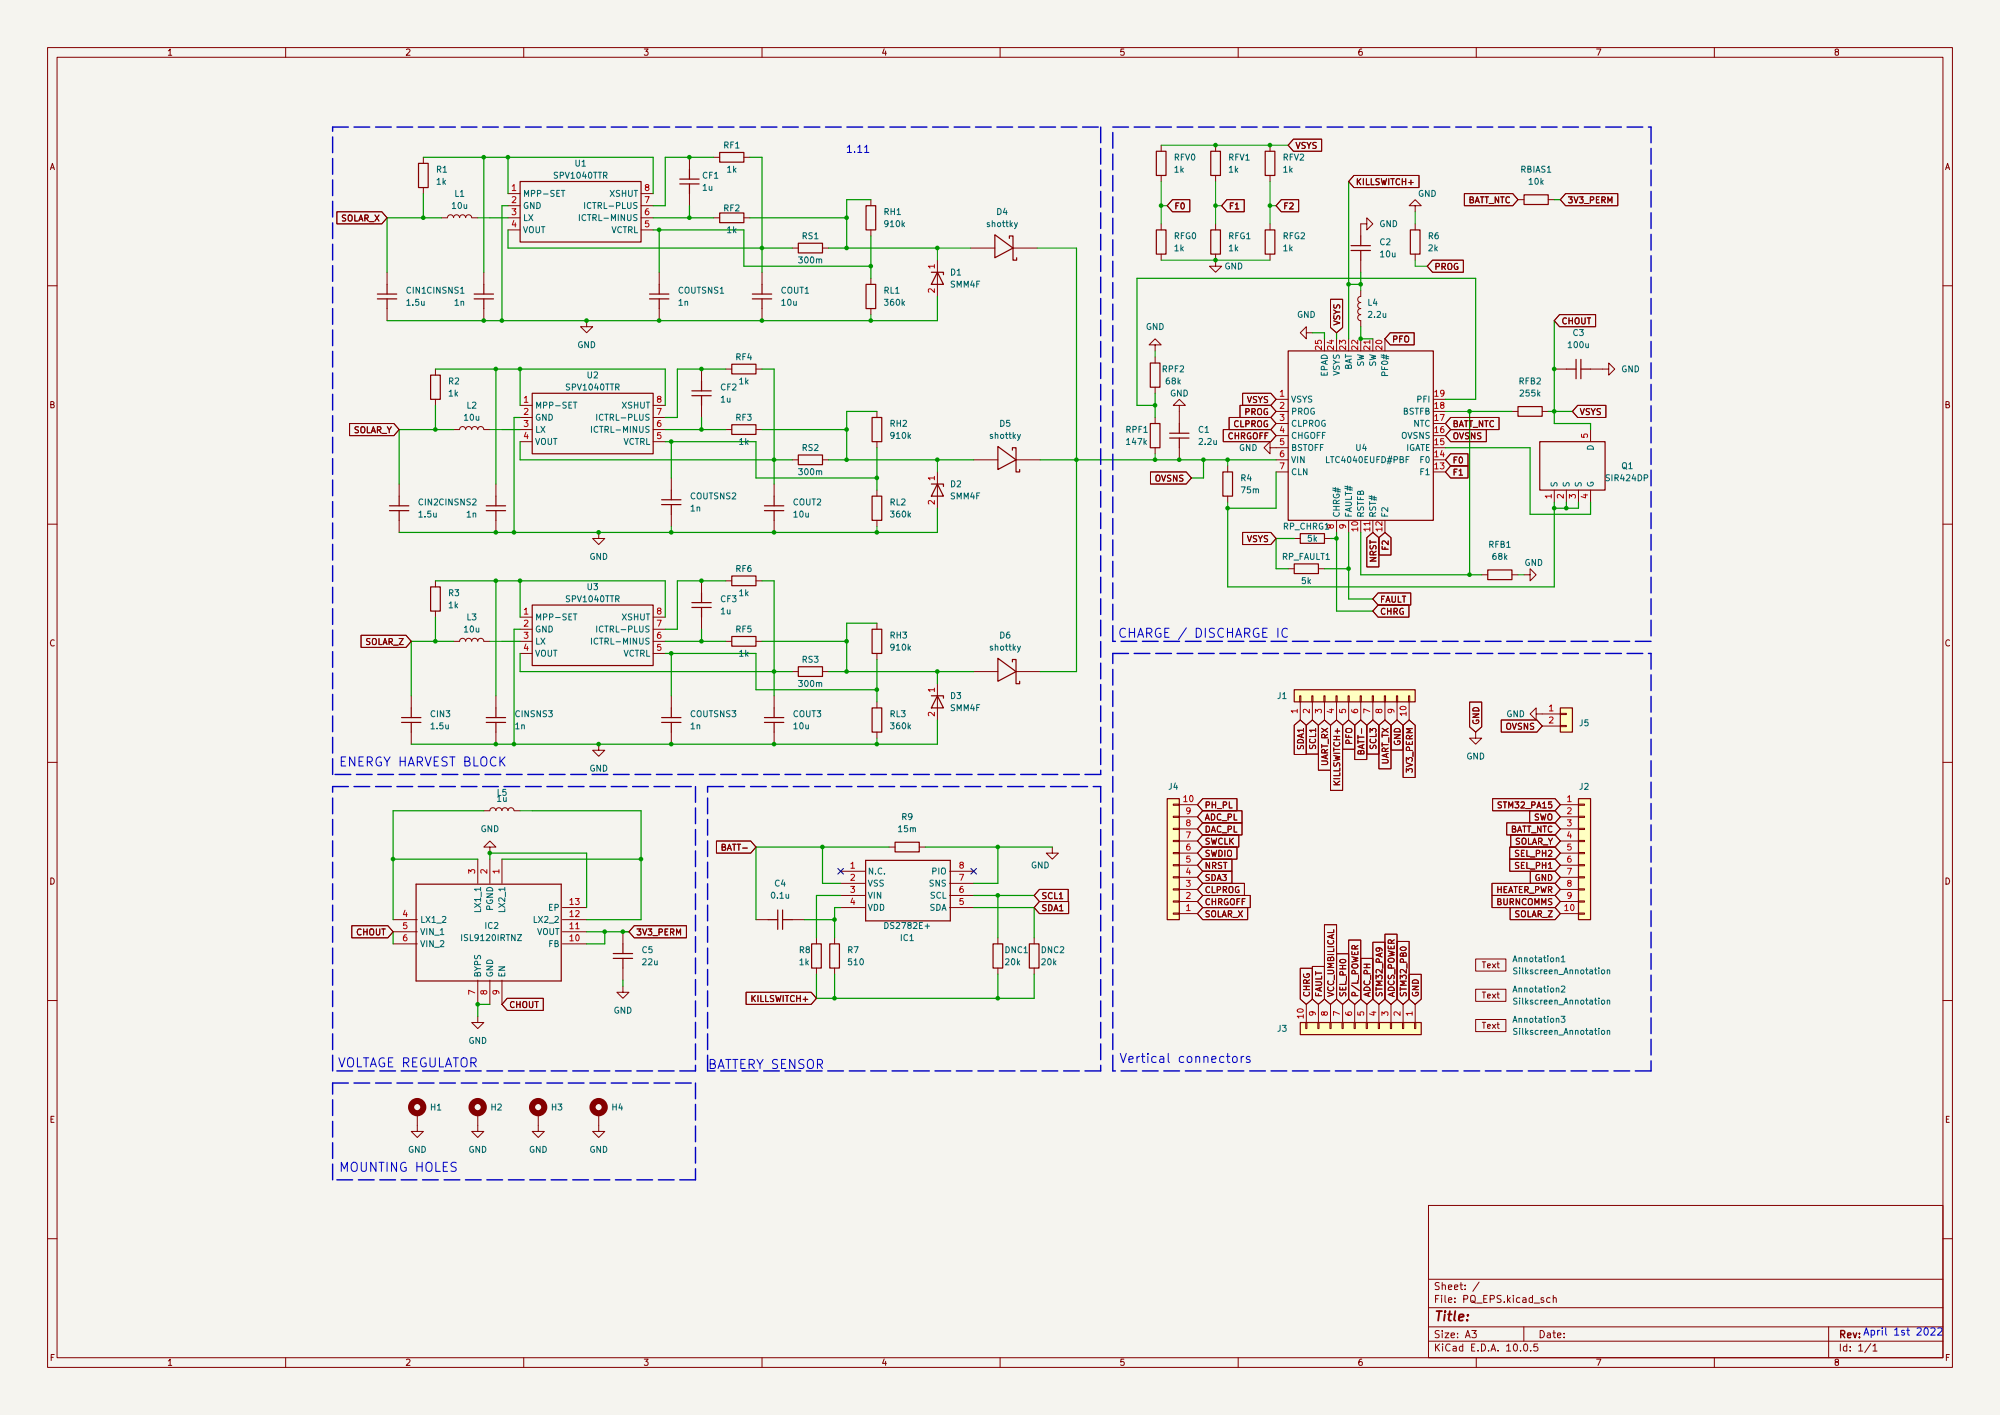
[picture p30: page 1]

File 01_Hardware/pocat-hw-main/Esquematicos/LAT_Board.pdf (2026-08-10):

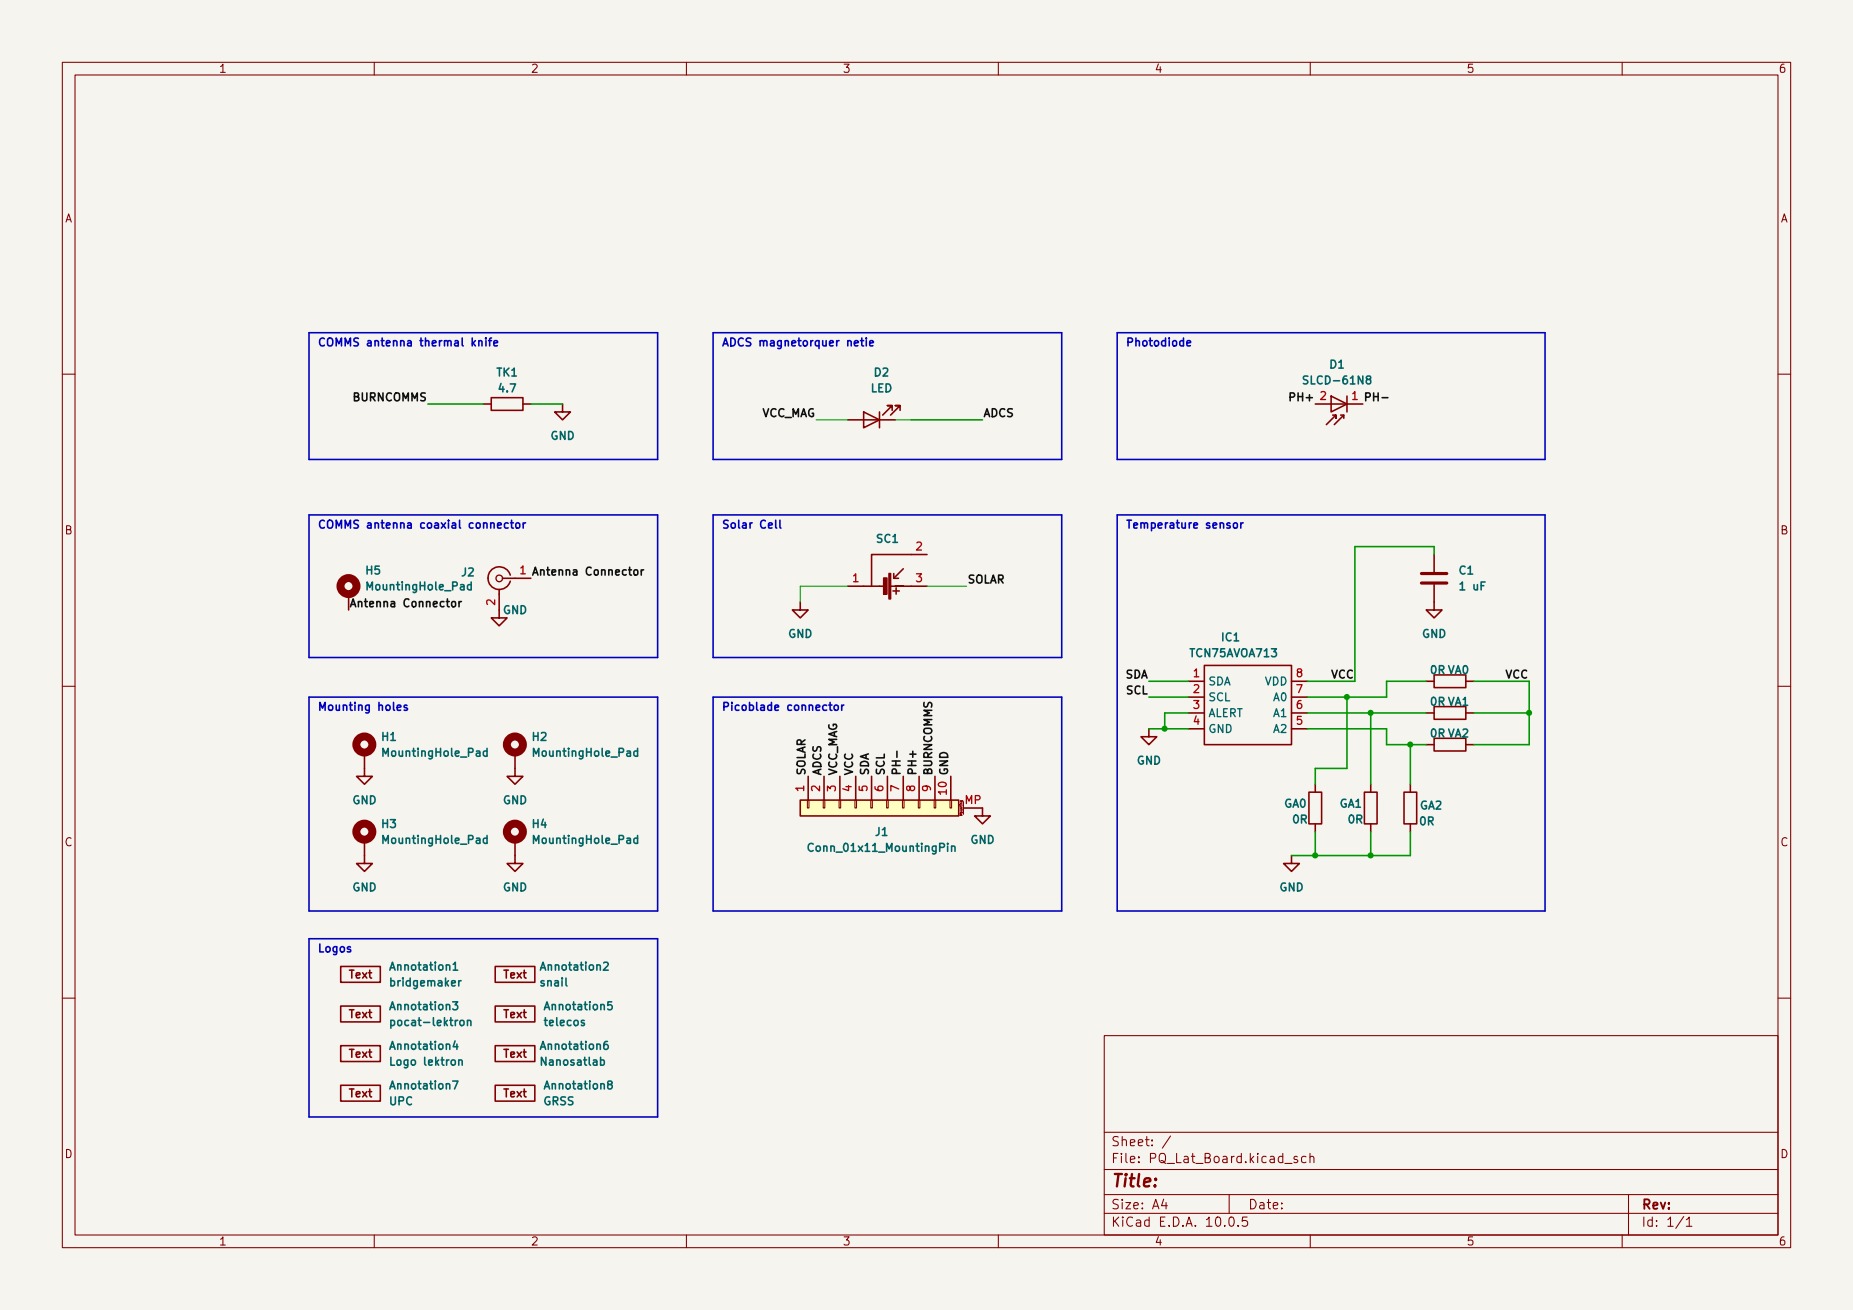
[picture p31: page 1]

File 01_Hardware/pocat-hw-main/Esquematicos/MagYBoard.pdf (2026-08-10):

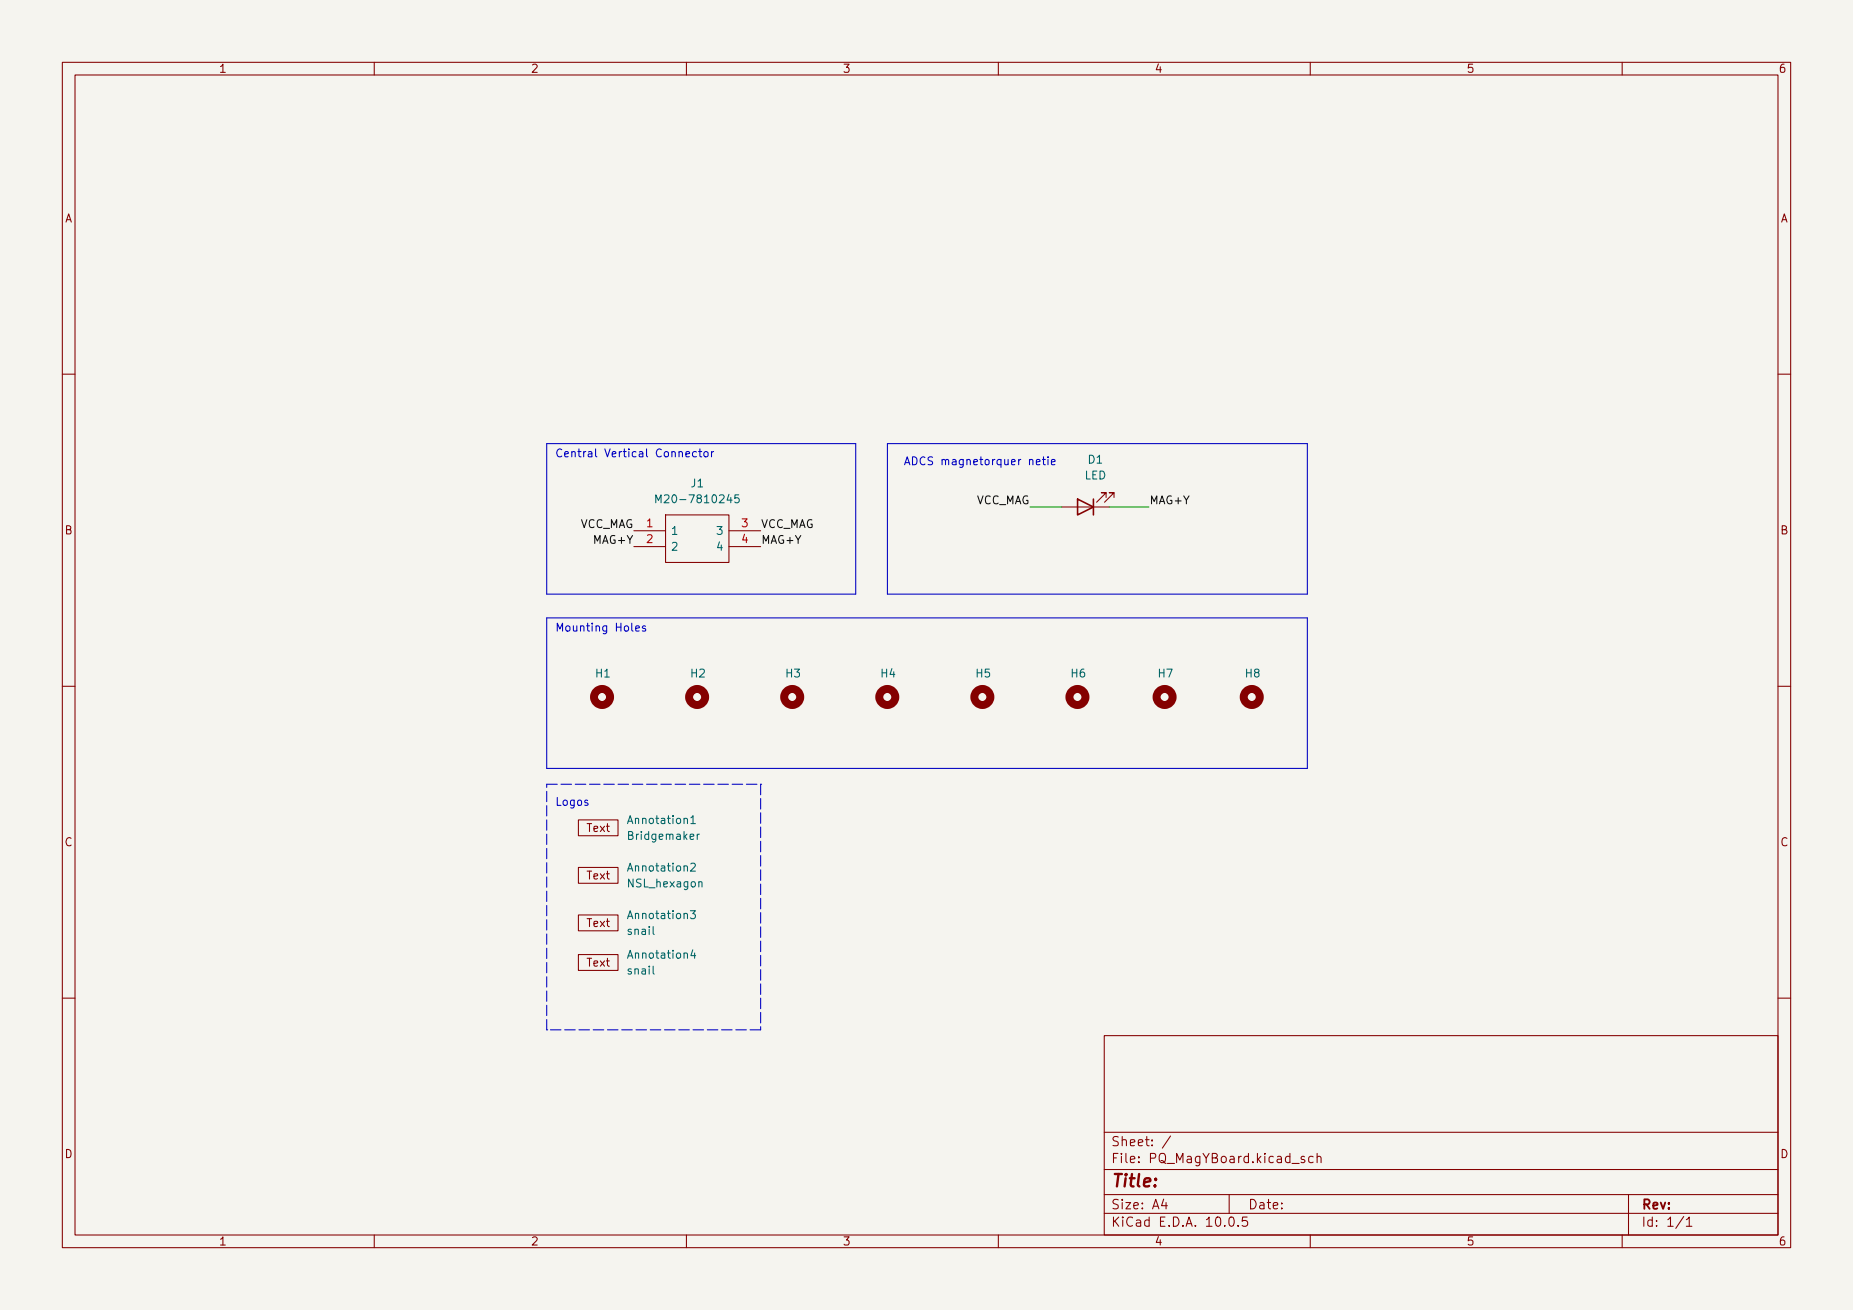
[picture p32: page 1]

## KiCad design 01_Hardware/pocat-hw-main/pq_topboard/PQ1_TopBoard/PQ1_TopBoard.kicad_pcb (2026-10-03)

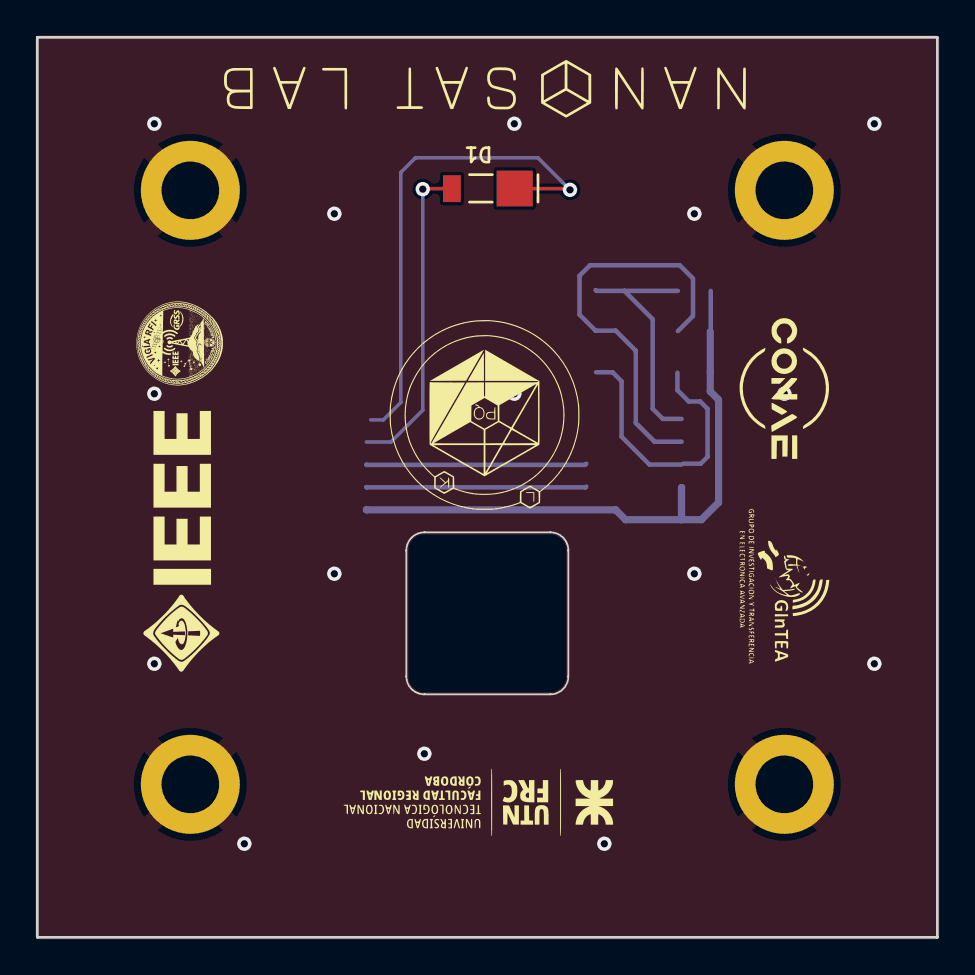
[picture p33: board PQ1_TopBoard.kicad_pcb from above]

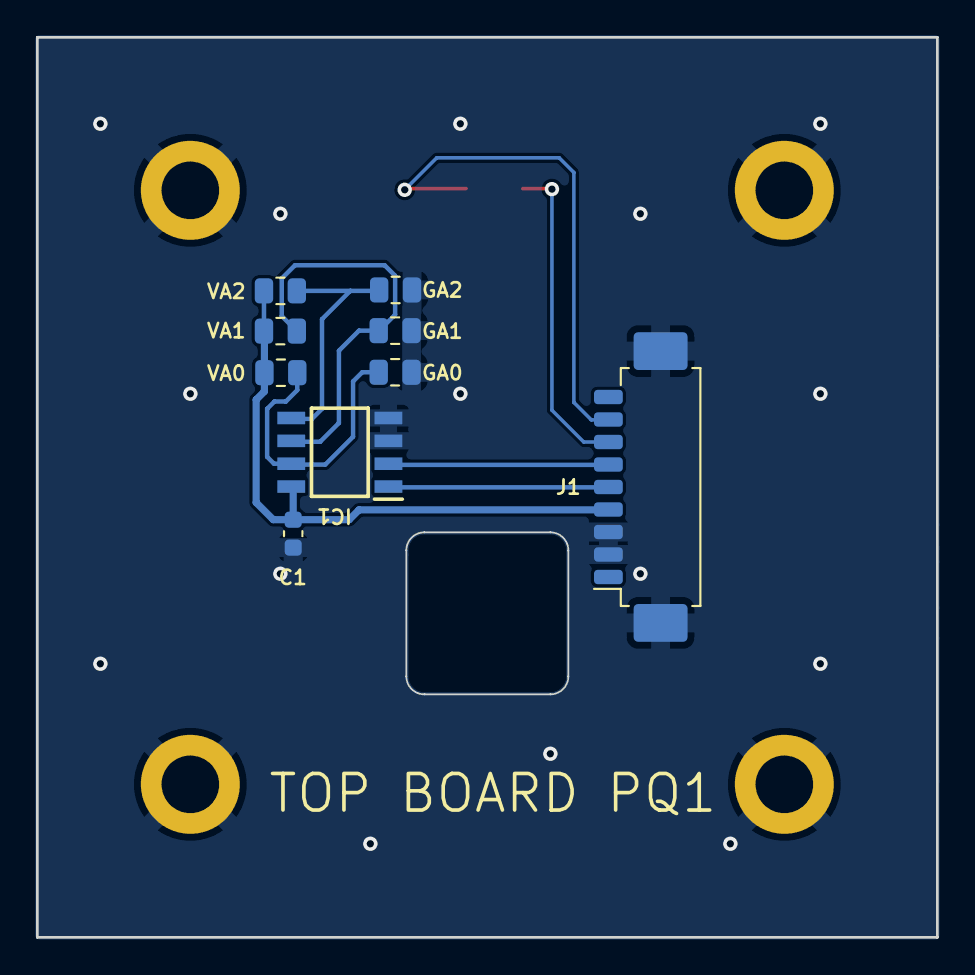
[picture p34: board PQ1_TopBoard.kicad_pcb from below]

Board: 2 copper layers, 50.0 x 50.0 mm, 17 parts (9 on the bottom side), 9 nets.

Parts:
Annotation1: Silkscreen_Annotation; IEEE_logo
Annotation3: Silkscreen_Annotation; NSL_long
Annotation6: Silkscreen_Annotation; NSL_Lektron
C1: 1 uF; C_0603_1608Metric
D1: SLCD-61N8
GA0, GA1, GA2: 0R; R_0805_2012Metric
H1, H2, H3, H4: MountingHole_Pad; MountingHole_3.2mm_M3_ISO14580_Pad
IC1: TCN75AVUA713; TCN75AVOA
J1: Conn_01x11_MountingPin; Molex_PicoBlade_53261-0971_1x09-1MP_P1.25mm_Horizontal
VA0, VA1, VA2: 0R; R_0805_2012Metric

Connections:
/3V3_PERM: C1.1, IC1.8 (VDD), J1.4, VA0.2, VA1.2, VA2.2
/PH+: D1.2, J1.8
/PH-: D1.1, J1.7
/SCL: IC1.2 (SCL), J1.6
/SDA: IC1.1 (SDA), J1.5
GND: C1.2, GA0.2, GA1.2, GA2.2, H1.1, H2.1, H3.1, H4.1, IC1.3 (ALERT), IC1.4 (GND), J1.2, J1.3, J1.MP (MountPin)
unnamed: GA0.1, IC1.7 (A0), VA0.1
unnamed: GA1.1, IC1.6 (A1), VA1.1
unnamed: GA2.1, IC1.5 (A2), VA2.1

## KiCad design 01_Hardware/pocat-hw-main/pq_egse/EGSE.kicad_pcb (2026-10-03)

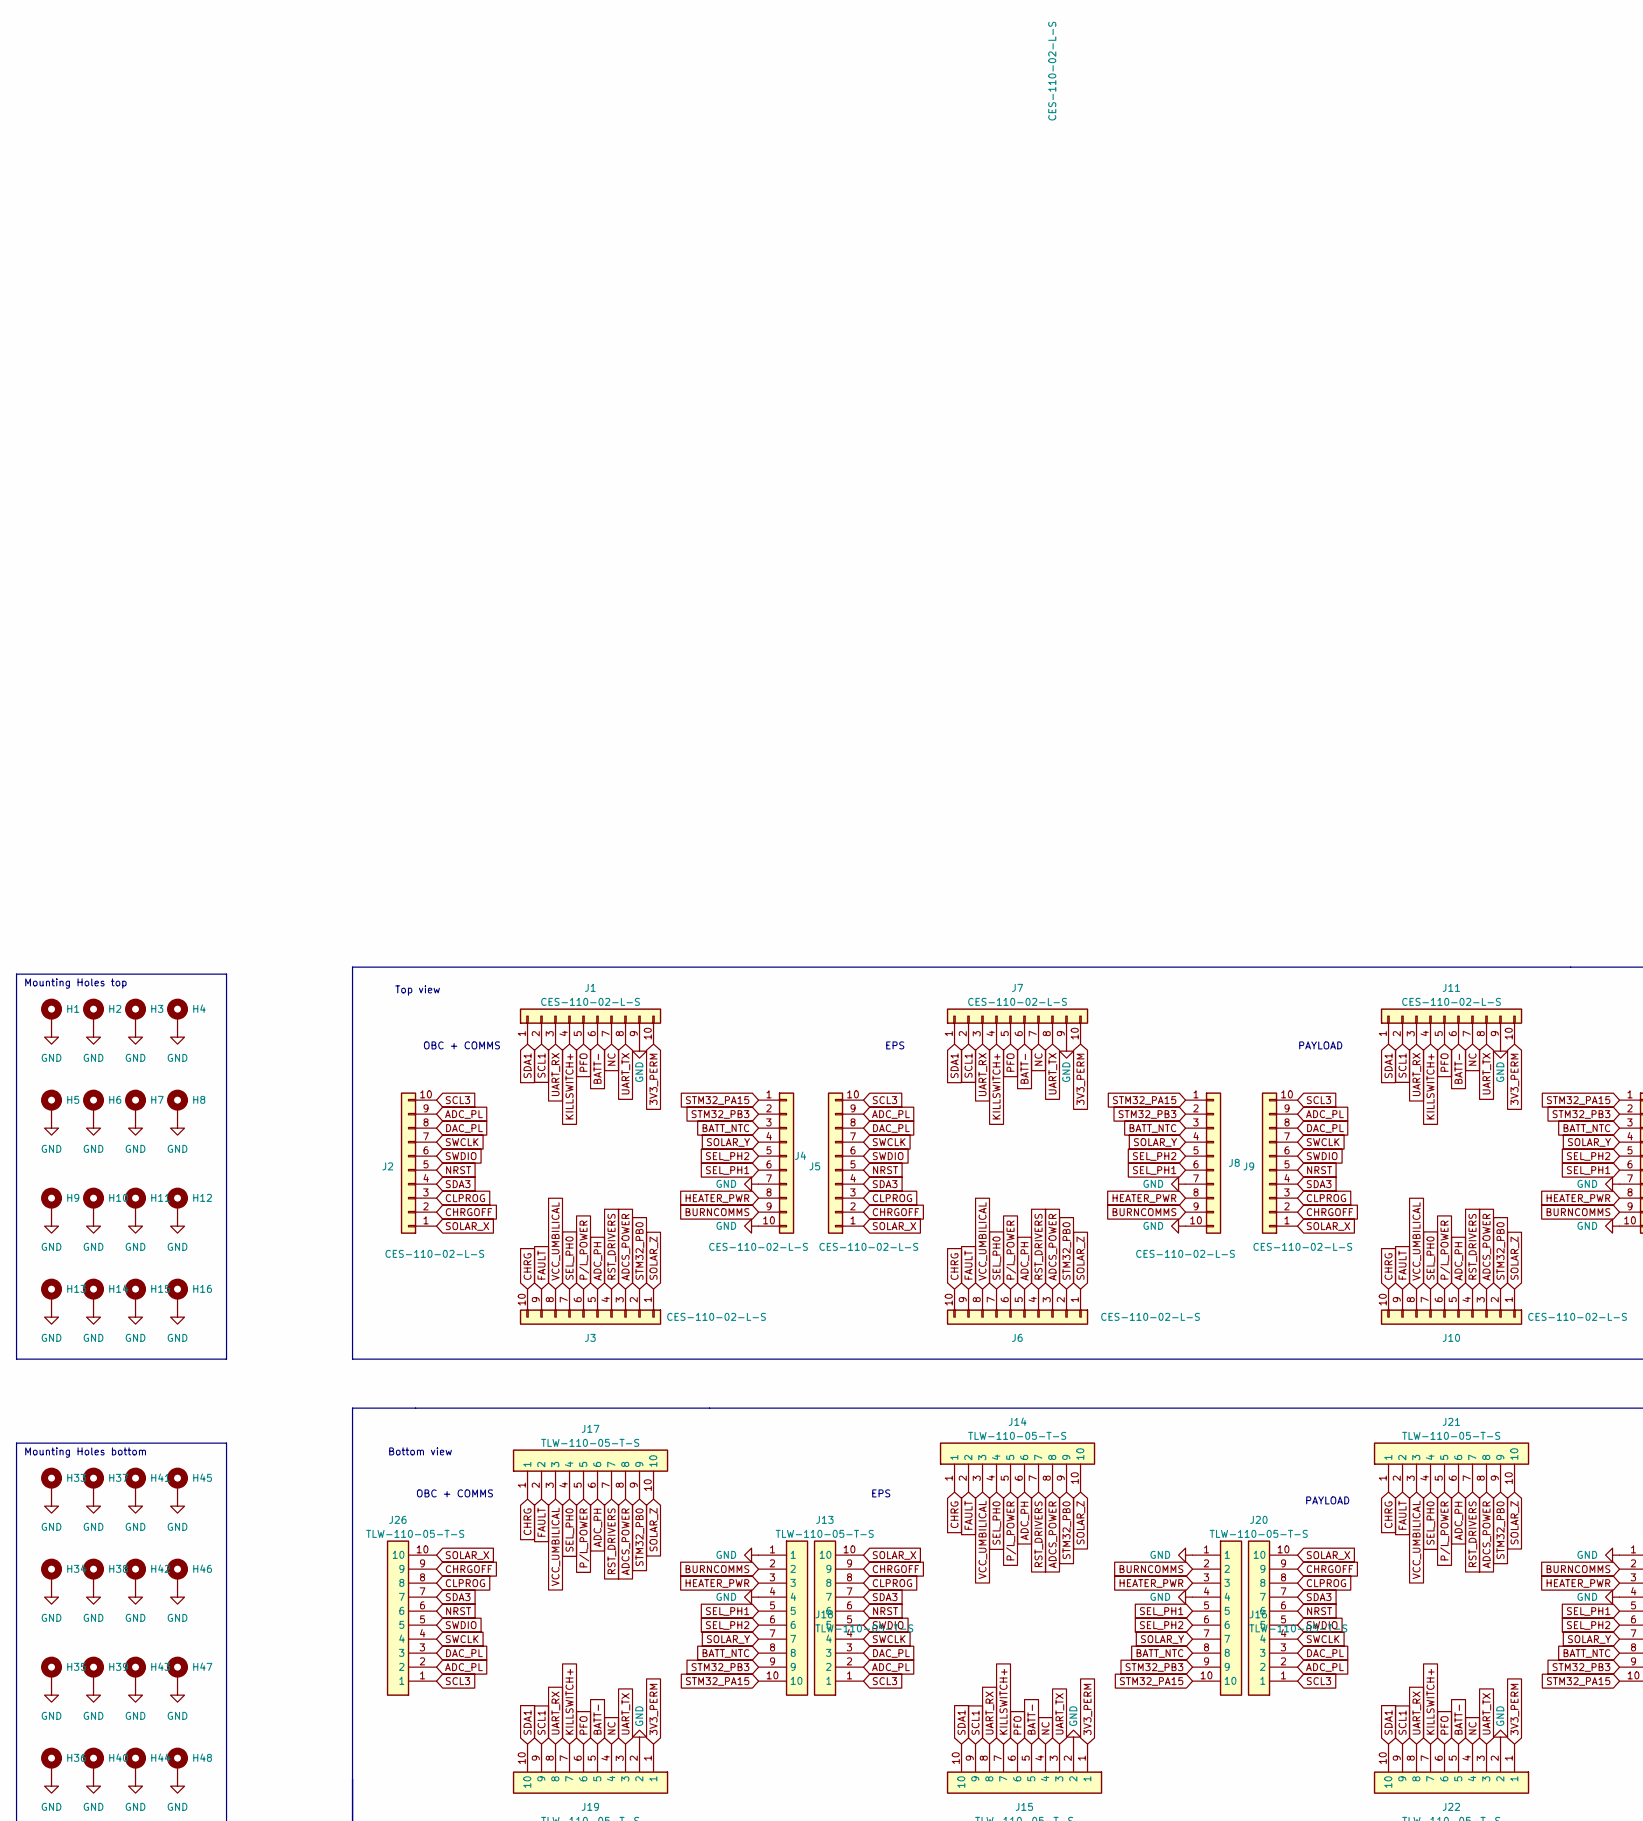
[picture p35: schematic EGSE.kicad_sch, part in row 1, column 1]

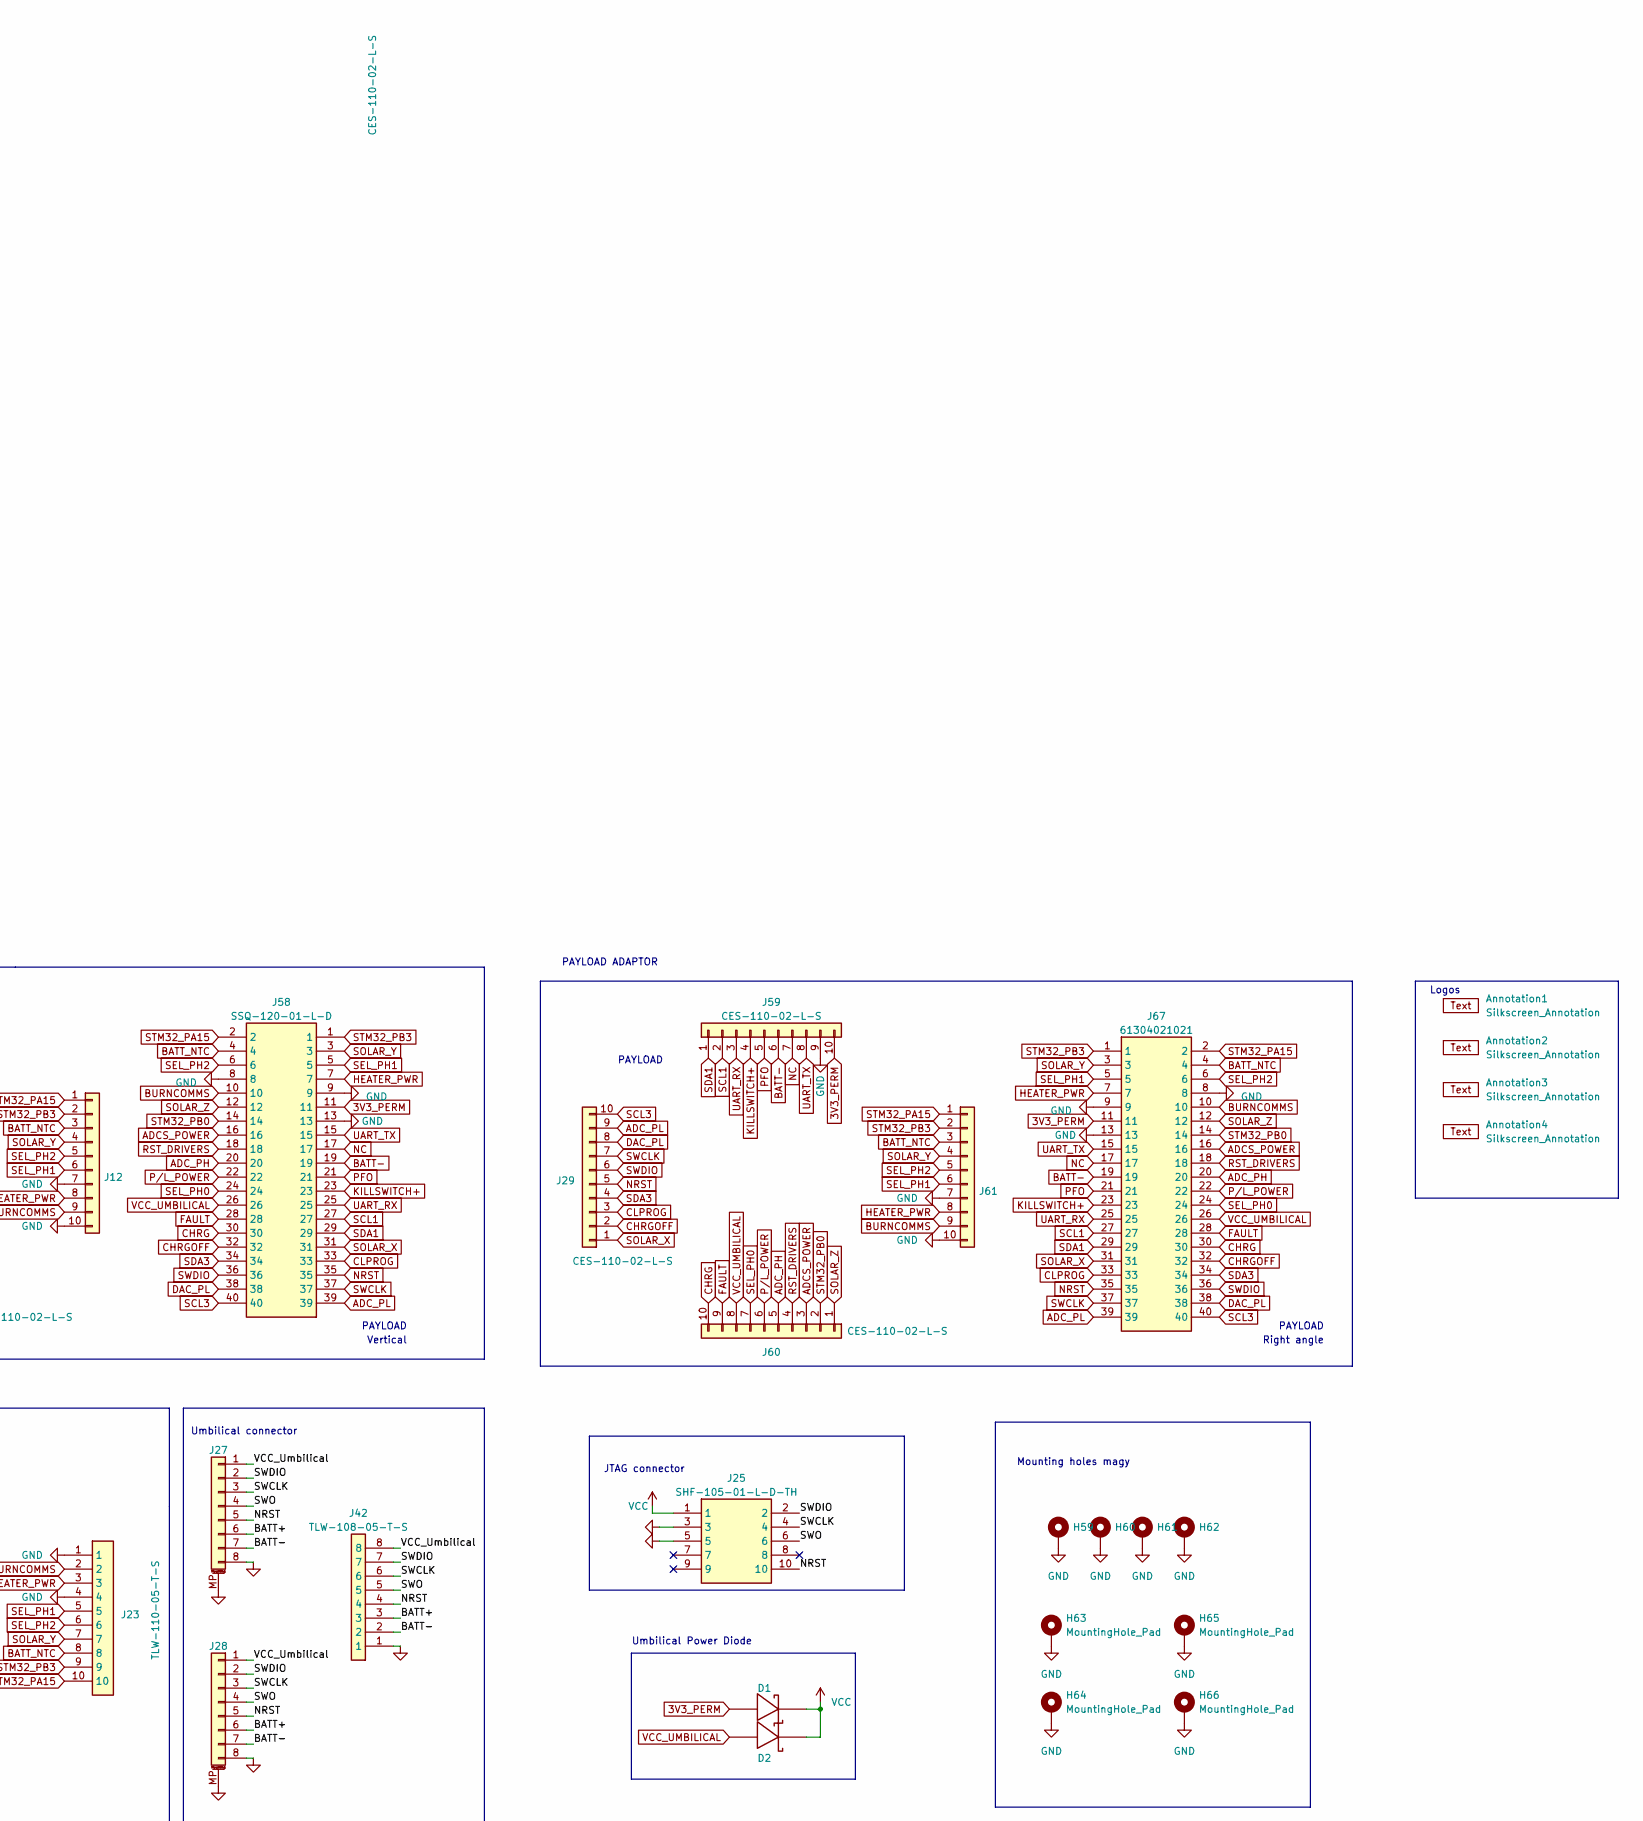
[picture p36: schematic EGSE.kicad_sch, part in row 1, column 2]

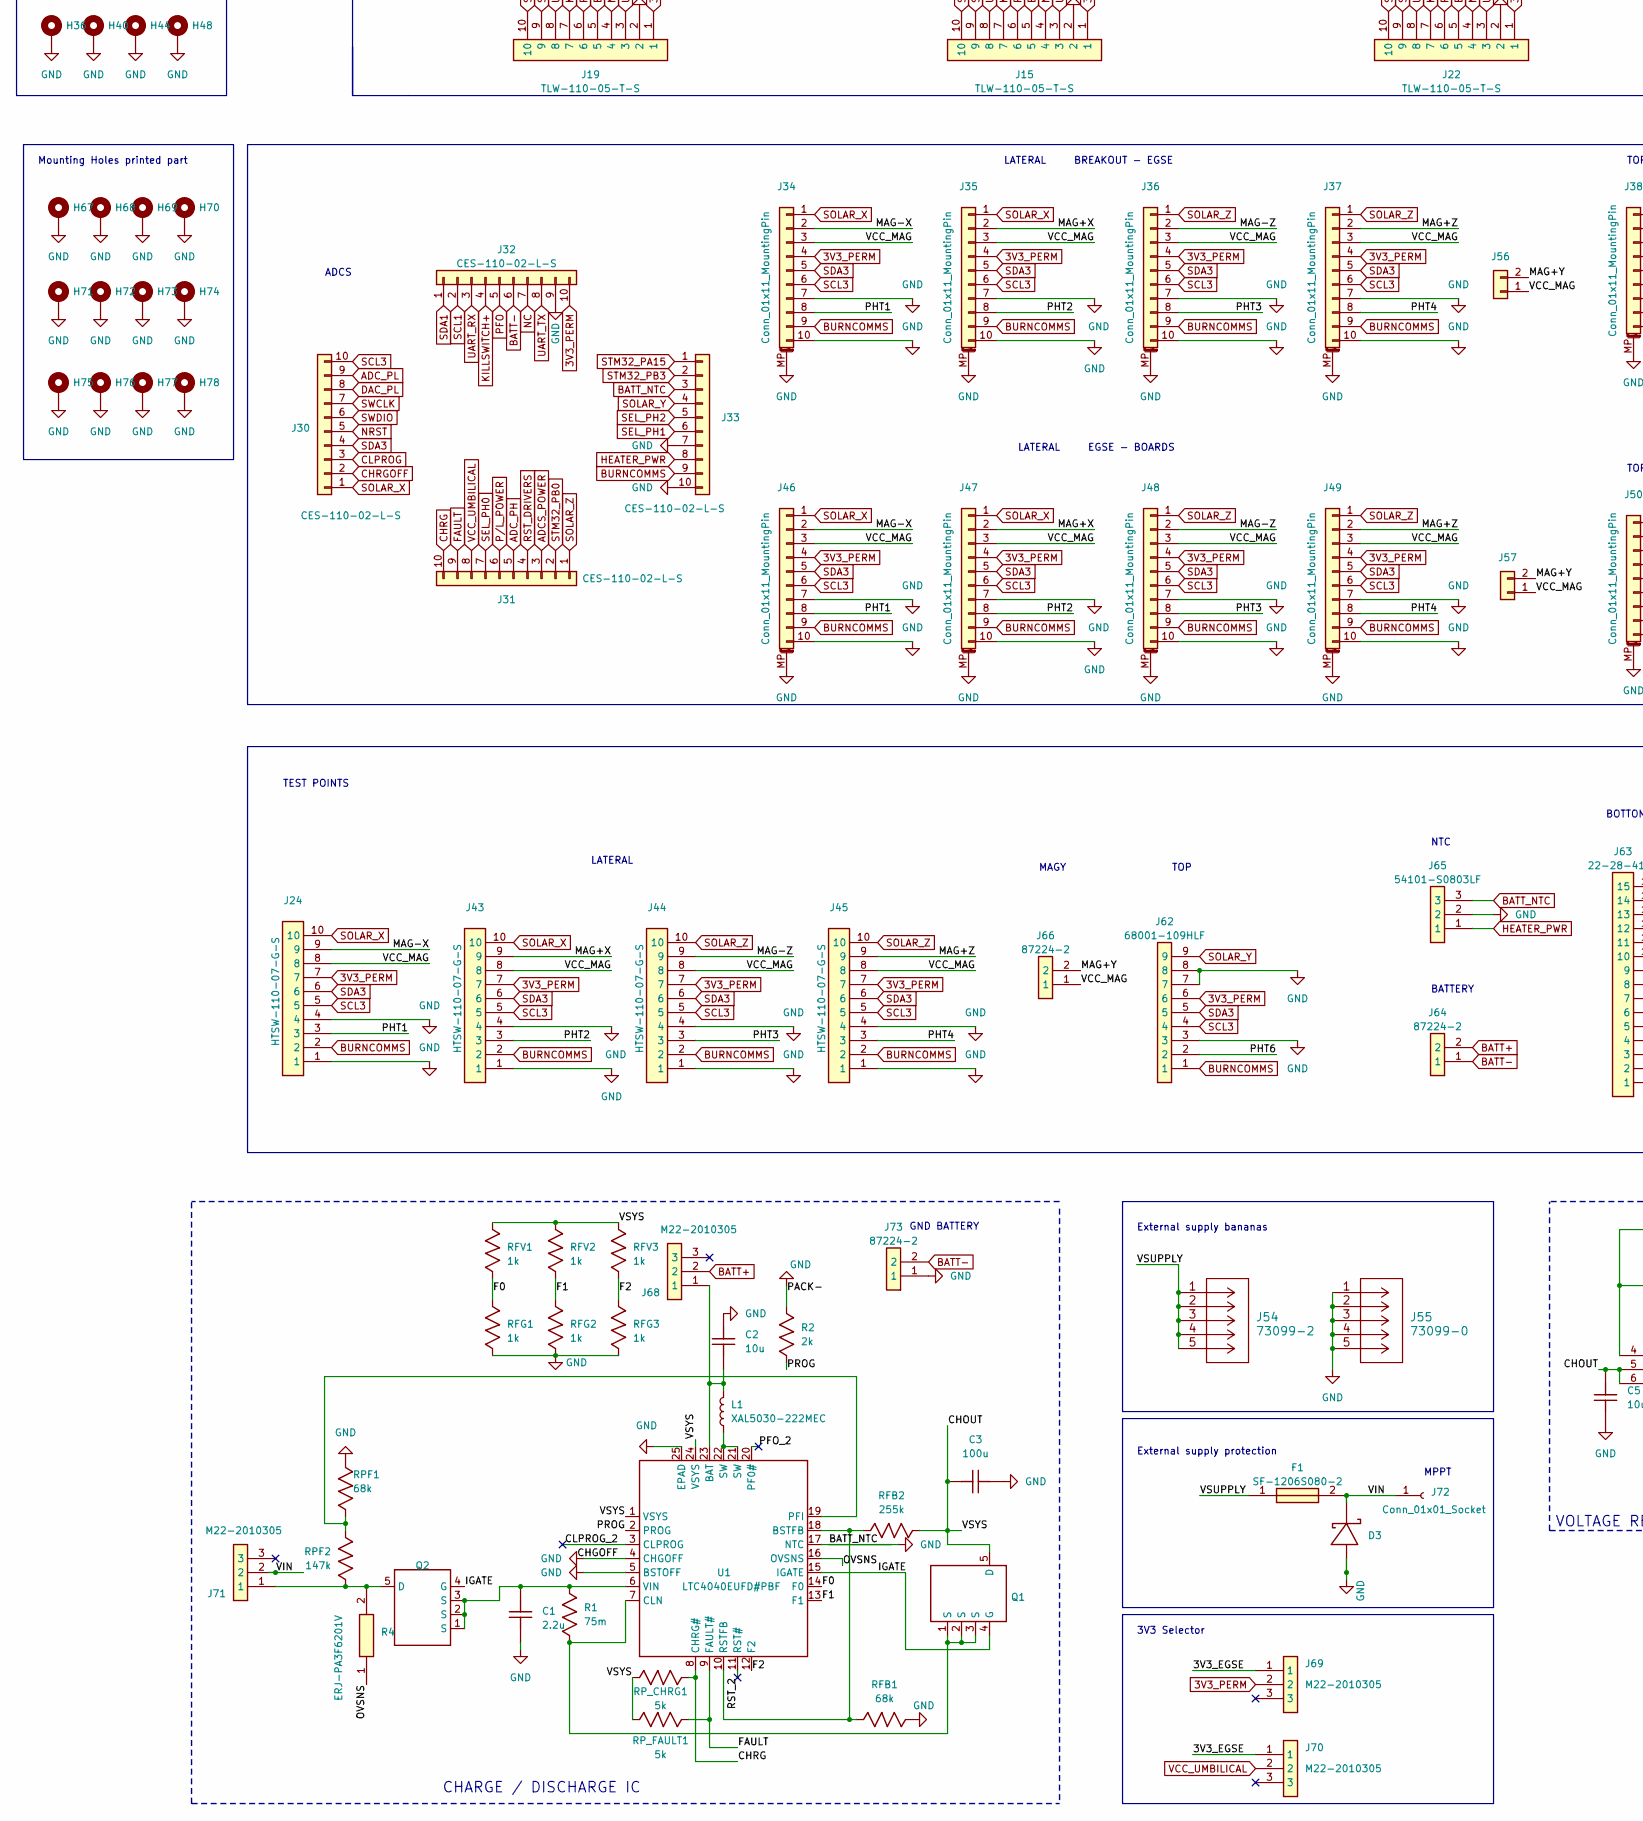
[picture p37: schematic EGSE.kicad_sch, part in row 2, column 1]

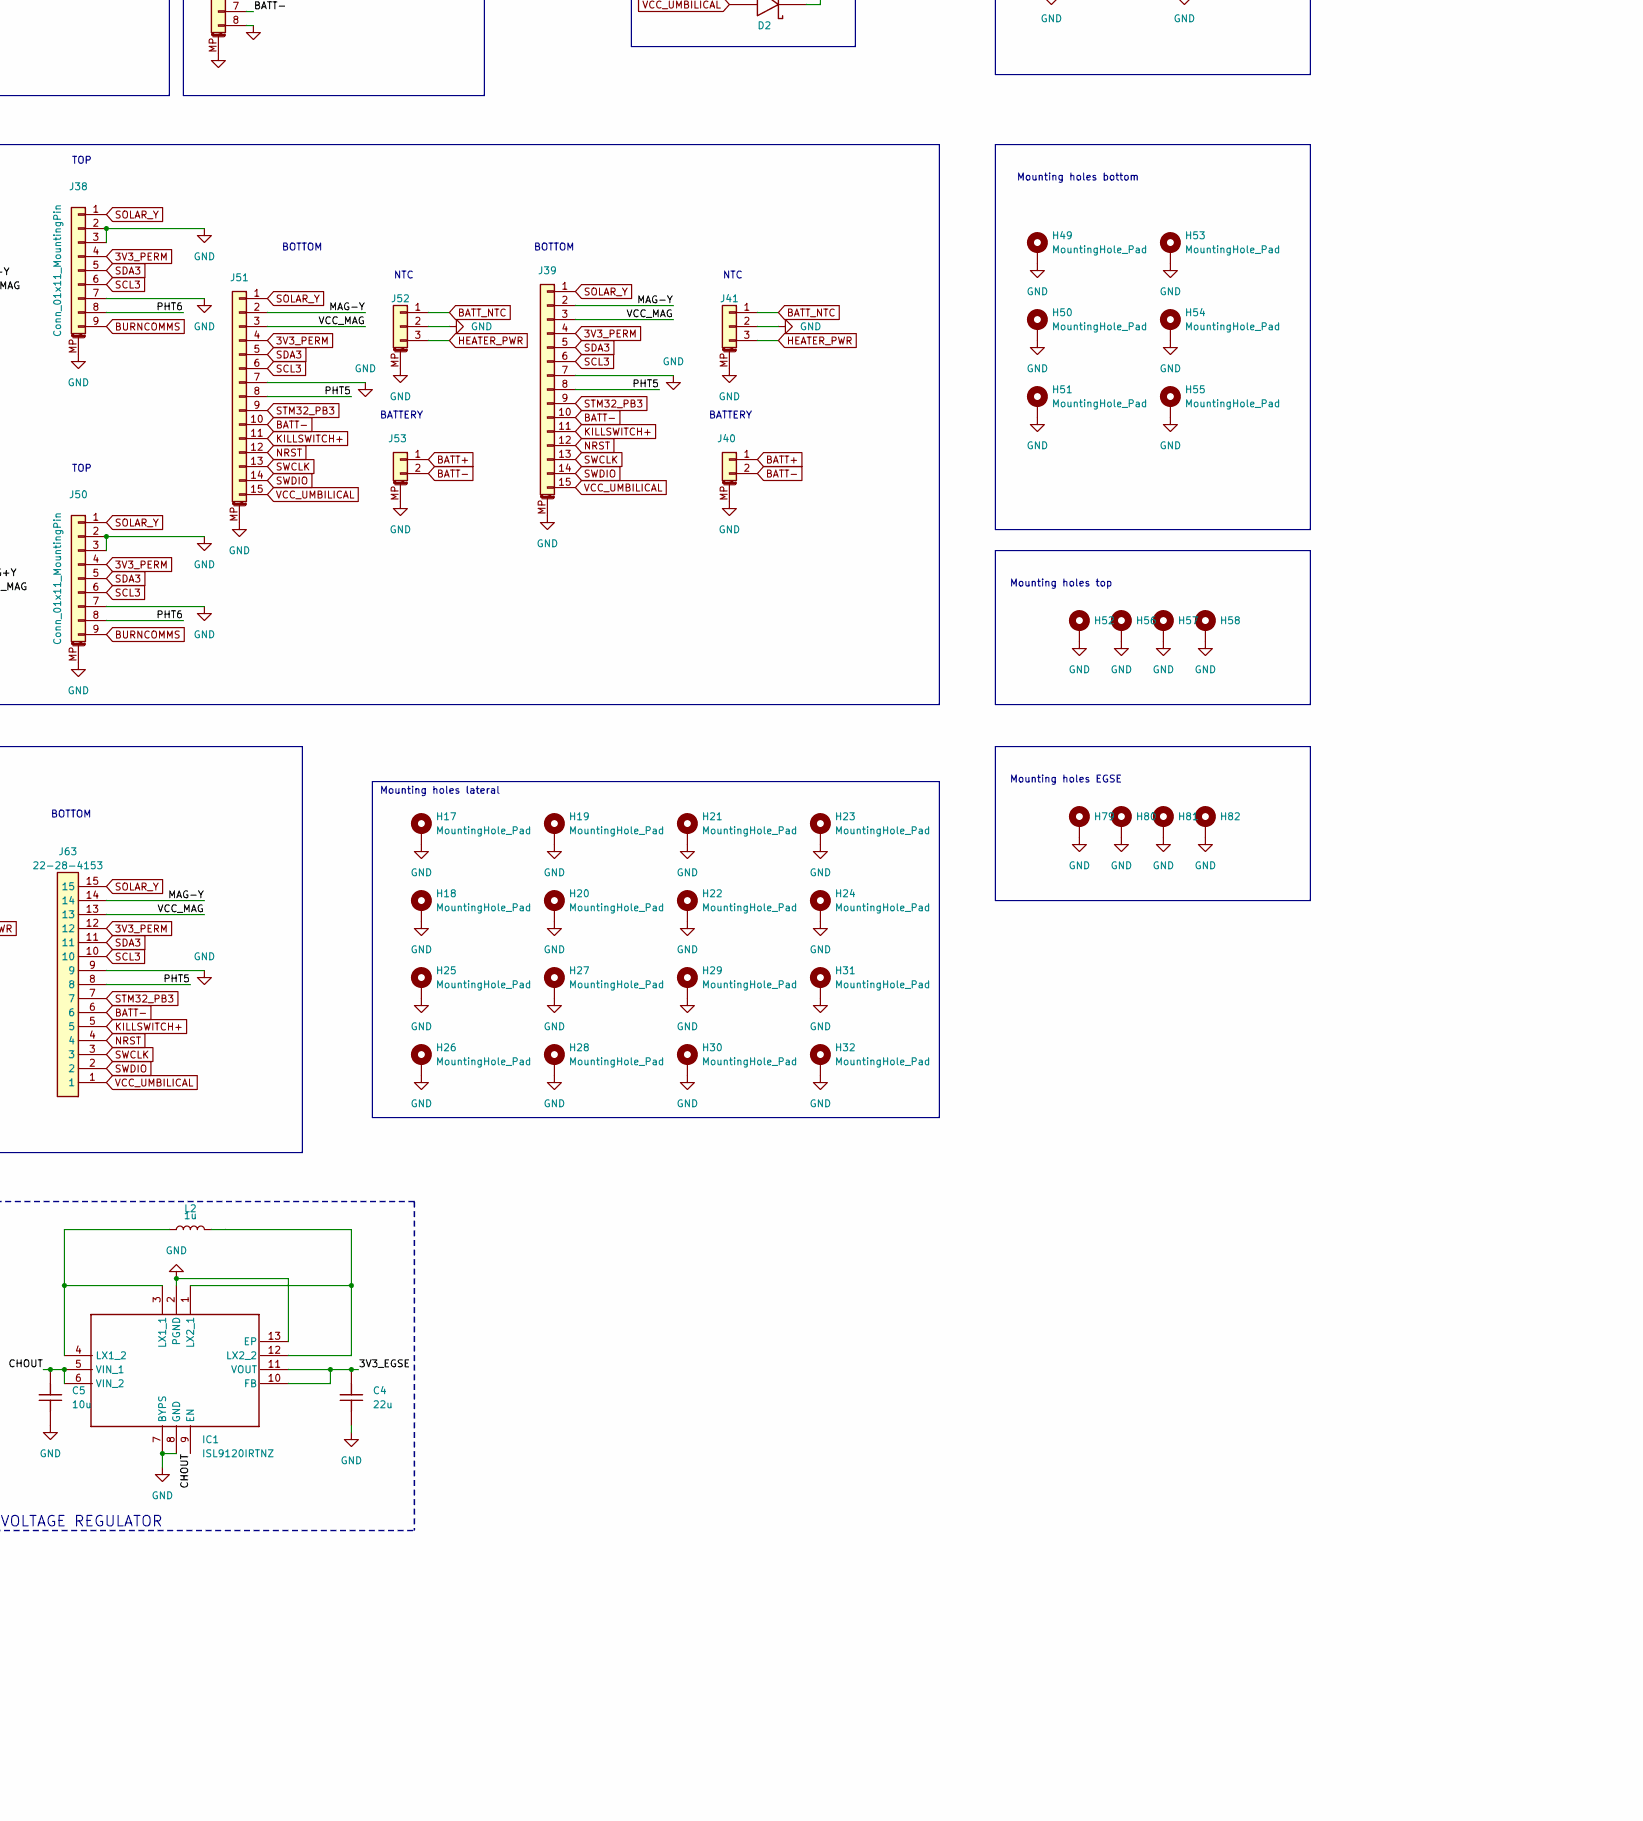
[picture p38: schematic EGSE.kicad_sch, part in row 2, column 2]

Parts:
Annotation1: Silkscreen_Annotation; Bridgemaker__Annotation1
Annotation2: Silkscreen_Annotation; IEEE_logo__Annotation2
Annotation3: Silkscreen_Annotation; NSL_long__Annotation3
Annotation4: Silkscreen_Annotation; Telecos__Annotation4
C1: 2.2u; C_0603_1608Metric__C1
C2: 10u; C_0603_1608Metric__C2
C3: 100u; C_1206_3216Metric__C3
C4: 22u; C_0603_1608Metric__C4
C5: 10u; C_0603_1608Metric__C5
D1, D2, D3: type="D" model="RBS1LAM40ATR" lib=""; RBS1LAM40ATR_Schottky; Manufacturer Part Numbe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 RBS1LAM40ATR
F1: SF-1206S080-2; FUSC3116X70N__F1; Mouser Part Number 652-SF-1206S080-2
H1: MountingHole_Pad; MountingHole_3.2mm_M3_Pad__H1
H2: MountingHole_Pad; MountingHole_3.2mm_M3_Pad__H2
H3: MountingHole_Pad; MountingHole_3.2mm_M3_Pad__H3
H4: MountingHole_Pad; MountingHole_3.2mm_M3_Pad__H4
H5: MountingHole_Pad; MountingHole_3.2mm_M3_Pad__H5
H6: MountingHole_Pad; MountingHole_3.2mm_M3_Pad__H6
H7: MountingHole_Pad; MountingHole_3.2mm_M3_Pad__H7
H8: MountingHole_Pad; MountingHole_3.2mm_M3_Pad__H8
H9: MountingHole_Pad; MountingHole_3.2mm_M3_Pad__H9
H10: MountingHole_Pad; MountingHole_3.2mm_M3_Pad__H10
H11: MountingHole_Pad; MountingHole_3.2mm_M3_Pad__H11
H12: MountingHole_Pad; MountingHole_3.2mm_M3_Pad__H12
H13: MountingHole_Pad; MountingHole_3.2mm_M3_Pad__H13
H14: MountingHole_Pad; MountingHole_3.2mm_M3_Pad__H14
H15: MountingHole_Pad; MountingHole_3.2mm_M3_Pad__H15
H16: MountingHole_Pad; MountingHole_3.2mm_M3_Pad__H16
H17, H18, H19, H20, H21, H22, H23, H24, H25, H26, H27, H28, H29, H30, H31, H32, H49, H50, H51, H53, H54, H55, H63, H64, H65, H66: MountingHole_Pad; MountingHole_2.2mm_M2_Pad
H33, H34, H35, H36, H37, H38, H39, H40, H41, H42, H43, H44, H45, H46, H47, H48, H52, H56, H57, H58, H59, H60, H67, H70, H71, H72, H73, H74, H75, H76, H77, H78, H79, H80, H81, H82: MountingHole_Pad; MountingHole_3.2mm_M3_Pad
H61: MountingHole_Pad; MountingHole_3.2mm_M3_Pad__H61
H62: MountingHole_Pad; MountingHole_3.2mm_M3_Pad__H62
H68: MountingHole_Pad; MountingHole_3.2mm_M3_Pad__H68
H69: MountingHole_Pad; MountingHole_3.2mm_M3_Pad__H69
IC1: ISL9120IRTNZ
J1: CES-110-02-L-S; PinSocket_1x10_P2.54mm_Vertical__J1; Manufacturer Part Numbe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 CES-110-02-L-S
J2: CES-110-02-L-S; PinSocket_1x10_P2.54mm_Vertical__J2; Manufacturer Part Numbe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 CES-110-02-L-S
J3: CES-110-02-L-S; PinSocket_1x10_P2.54mm_Vertical__J3; Manufacturer Part Numbe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 CES-110-02-L-S
J4: CES-110-02-L-S; PinSocket_1x10_P2.54mm_Vertical__J4; Manufacturer Part Numbe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 CES-110-02-L-S
J5: CES-110-02-L-S; PinSocket_1x10_P2.54mm_Vertical__J5; Manufacturer Part Numbe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 CES-110-02-L-S
J6: CES-110-02-L-S; PinSocket_1x10_P2.54mm_Vertical__J6; Manufacturer Part Numbe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 CES-110-02-L-S
J7: CES-110-02-L-S; PinSocket_1x10_P2.54mm_Vertical__J7; Manufacturer Part Numbe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 CES-110-02-L-S
J8: CES-110-02-L-S; PinSocket_1x10_P2.54mm_Vertical__J8; Manufacturer Part Numbe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 CES-110-02-L-S
J9: CES-110-02-L-S; PinSocket_1x10_P2.54mm_Vertical__J9; Manufacturer Part Numbe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 CES-110-02-L-S
J10: CES-110-02-L-S; PinSocket_1x10_P2.54mm_Vertical__J10; Manufacturer Part Numbe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 CES-110-02-L-S
J11: CES-110-02-L-S; PinSocket_1x10_P2.54mm_Vertical__J11; Manufacturer Part Numbe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 CES-110-02-L-S
J12: CES-110-02-L-S; PinSocket_1x10_P2.54mm_Vertical__J12; Manufacturer Part Numbe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 CES-110-02-L-S
J13: TLW-110-05-T-S; HDRV10W64P0X254_1X10_2540X248X838P__J13; Mouser Part Number 200-HTSW11007GS
J14: TLW-110-05-T-S; HDRV10W64P0X254_1X10_2540X248X838P__J14; Mouser Part Number 200-HTSW11007GS
J15: TLW-110-05-T-S; HDRV10W64P0X254_1X10_2540X248X838P__J15; Mouser Part Number 200-HTSW11007GS
J16: TLW-110-05-T-S; HDRV10W64P0X254_1X10_2540X248X838P__J16; Mouser Part Number 200-HTSW11007GS
J17: TLW-110-05-T-S; HDRV10W64P0X254_1X10_2540X248X838P__J17; Mouser Part Number 200-HTSW11007GS
J18: TLW-110-05-T-S; HDRV10W64P0X254_1X10_2540X248X838P__J18; Mouser Part Number 200-HTSW11007GS
J19: TLW-110-05-T-S; HDRV10W64P0X254_1X10_2540X248X838P__J19; Mouser Part Number 200-HTSW11007GS
J20: TLW-110-05-T-S; HDRV10W64P0X254_1X10_2540X248X838P__J20; Mouser Part Number 200-HTSW11007GS
J21: TLW-110-05-T-S; HDRV10W64P0X254_1X10_2540X248X838P__J21; Mouser Part Number 200-HTSW11007GS
J22: TLW-110-05-T-S; HDRV10W64P0X254_1X10_2540X248X838P__J22; Mouser Part Number 200-HTSW11007GS
J23: TLW-110-05-T-S; HDRV10W64P0X254_1X10_2540X248X838P__J23; Mouser Part Number 200-HTSW11007GS
J24: HTSW-110-07-G-S; HDRV10W64P0X254_1X10_2540X248X838P__J24; Mouser Part Number 200-HTSW11007GS
J25: SHF-105-01-L-D-TH; SHF10501LDTH__J25; Mouser Part Number 200-SHF10501LDTH
J26: TLW-110-05-T-S; HDRV10W64P0X254_1X10_2540X248X838P__J26; Mouser Part Number 200-HTSW11007GS
J27: Conn_01x08_MountingPin; Molex_PicoBlade_53398-0871_1x08-1MP_P1.25mm_Vertical__J27
J28: Conn_01x08_MountingPin; Molex_PicoBlade_53398-0871_1x08-1MP_P1.25mm_Vertical__J28
J29: CES-110-02-L-S; PinSocket_1x10_P2.54mm_Vertical__J29; Manufacturer Part Numbe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 CES-110-02-L-S
J30: CES-110-02-L-S; PinSocket_1x10_P2.54mm_Vertical__J30; Manufacturer Part Numbe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 CES-110-02-L-S
J31: CES-110-02-L-S; PinSocket_1x10_P2.54mm_Vertical__J31; Manufacturer Part Numbe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 CES-110-02-L-S
J32: CES-110-02-L-S; PinSocket_1x10_P2.54mm_Vertical__J32; Manufacturer Part Numbe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 CES-110-02-L-S
J33: CES-110-02-L-S; PinSocket_1x10_P2.54mm_Vertical__J33; Manufacturer Part Numbe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 CES-110-02-L-S
J34: Conn_01x11_MountingPin; Molex_PicoBlade_53261-1071_1x10-1MP_P1.25mm_Horizontal__J34
J35: Conn_01x11_MountingPin; Molex_PicoBlade_53261-1071_1x10-1MP_P1.25mm_Horizontal__J35
J36: Conn_01x11_MountingPin; Molex_PicoBlade_53261-1071_1x10-1MP_P1.25mm_Horizontal__J36
J37: Conn_01x11_MountingPin; Molex_PicoBlade_53261-1071_1x10-1MP_P1.25mm_Horizontal__J37
J38: Conn_01x11_MountingPin; Molex_PicoBlade_53261-0971_1x09-1MP_P1.25mm_Horizontal__J38
J39: 53261-1471; Molex_PicoBlade_53261-1571_1x15-1MP_P1.25mm_Horizontal__J39
J40: 53261-0271; Molex_PicoBlade_53261-0271_1x02-1MP_P1.25mm_Horizontal__J40
J41: Pico-Clasp_01x03; Picoclasp03__J41; Manufacturer Part Numbe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 203556-0307
J42: TLW-108-05-T-S; SAMTEC_TLW-108-05-T-S__J42; Mouser Part Number 200-TLW10805TS
J43: HTSW-110-07-G-S; HDRV10W64P0X254_1X10_2540X248X838P__J43; Mouser Part Number 200-HTSW11007GS
J44: HTSW-110-07-G-S; HDRV10W64P0X254_1X10_2540X248X838P__J44; Mouser Part Number 200-HTSW11007GS
J45: HTSW-110-07-G-S; HDRV10W64P0X254_1X10_2540X248X838P__J45; Mouser Part Number 200-HTSW11007GS
J46: Conn_01x11_MountingPin; Molex_PicoBlade_53261-1071_1x10-1MP_P1.25mm_Horizontal__J46
J47: Conn_01x11_MountingPin; Molex_PicoBlade_53261-1071_1x10-1MP_P1.25mm_Horizontal__J47
J48: Conn_01x11_MountingPin; Molex_PicoBlade_53261-1071_1x10-1MP_P1.25mm_Horizontal__J48
J49: Conn_01x11_MountingPin; Molex_PicoBlade_53261-1071_1x10-1MP_P1.25mm_Horizontal__J49
J50: Conn_01x11_MountingPin; Molex_PicoBlade_53261-0971_1x09-1MP_P1.25mm_Horizontal__J50
J51: 53261-1471; Molex_PicoBlade_53261-1571_1x15-1MP_P1.25mm_Horizontal__J51
J52: Pico-Clasp_01x03; Picoclasp03__J52; Manufacturer Part Numbe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 203556-0307
J53: 53261-0271; Molex_PicoBlade_53261-0271_1x02-1MP_P1.25mm_Horizontal__J53
J54: 73099-2; 73099-2__J54
J55: 73099-0; 73099-2__J55
J56: CES-102-02-L-S; CES-102-02__J56; Manufacturer Part Numbe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 CES-102-02-L-S
J57: CES-102-02-L-S; CES-102-02__J57; Manufacturer Part Numbe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 CES-102-02-L-S
J58: SSQ-120-01-L-D; SSQ-120-XX-YYY-D__J58; Mouser Part Number 200-SSQ12001LD
J59: CES-110-02-L-S; PinSocket_1x10_P2.54mm_Vertical__J59; Manufacturer Part Numbe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 CES-110-02-L-S
J60: CES-110-02-L-S; PinSocket_1x10_P2.54mm_Vertical__J60; Manufacturer Part Numbe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 CES-110-02-L-S
J61: CES-110-02-L-S; PinSocket_1x10_P2.54mm_Vertical__J61; Manufacturer Part Numbe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 CES-110-02-L-S
J62: 68001-109HLF; HDRV9W90P0X254_1X9_2286X241X1143P__J62; Mouser Part Number 649-68001-109HLF
J63: 22-28-4153; HDRV15W66P0X254_1X15_3810X249X838P__J63; Mouser Part Number 538-22-28-4153
J64: 87224-2; 872242__J64; Mouser Part Number 571-872242
J65: 54101-S0803LF; 54101S0803LF__J65; Mouser Part Number 649-54101-S0803LF
J66: 87224-2; 872242__J66; Mouser Part Number 571-872242
J67: 61304021021; HDRRA40W64P254_2X20_5080X254X508P__J67; Mouser Part Number 710-61304021021
J68: M22-2010305; HDRV3W60P0X200_1X3_600X200X525P__J68; Mouser Part Number 855-M22-2010305
J69: M22-2010305; HDRV3W60P0X200_1X3_600X200X525P__J69; Mouser Part Number 855-M22-2010305
J70: M22-2010305; HDRV3W60P0X200_1X3_600X200X525P__J70; Mouser Part Number 855-M22-2010305
J71: M22-2010305; HDRV3W60P0X200_1X3_600X200X525P__J71; Mouser Part Number 855-M22-2010305
J72: Conn_01x01_Socket; Pin_D0.9mm_L10.0mm_W2.4mm_FlatFork__J72
J73: 87224-2; 872242__J73; Mouser Part Number 571-872242
L1: XAL5030-222MEC; XAL5030222MEC; Manufacturer_Part_Number XAL5030-222MEC; Mouser Part Number 994-XAL5030-222MEC
L2: 1u; L_0805_2012Metric__L2
Q1, Q2: SIR424DP
R1: 75m; R_0805_2012Metric__R1
R2: 2k; R_0603_1608Metric__R2
R4: ERJ-PA3F6201V; ERJP03_PA3__0603___R4; Mouser Part Number 667-ERJ-PA3F6201V
RFB1: 68k; R_0603_1608Metric__RFB1
RFB2: 255k; R_0402_1005Metric__RFB2
RFG1: 1k; R_0603_1608Metric__RFG1
RFG2: 1k; R_0603_1608Metric__RFG2
RFG3: 1k; R_0603_1608Metric__RFG3
RFV1: 1k; R_0603_1608Metric__RFV1
RFV2: 1k; R_0603_1608Metric__RFV2
RFV3: 1k; R_0603_1608Metric__RFV3
RPF1: 68k; R_0603_1608Metric__RPF1
RPF2: 147k; R_0603_1608Metric__RPF2
RP_CHRG1: 5k; R_0805_2012Metric__RP_CHRG1
RP_FAULT1: 5k; R_0805_2012Metric__RP_FAULT1
U1: LTC4040EUFD#PBF; QFN-24-1EP_4x5mm_P0.5mm_EP2.65x3.65mm__U1

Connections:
3V3_PERM: D1.2, J1.10, J7.10, J11.10, J15.1, J19.1, J22.1, J24.7, J32.10, J34.4, J35.4, J36.4, J37.4, J38.4, J39.4, J43.7, J44.7, J45.7, J46.4, J47.4, J48.4, J49.4, J50.4, J51.4, J58.11, J59.10, J62.6, J63.12, J67.11, J69.2
/3V3_EGSE: C4.2, IC1.10 (FB), IC1.11 (VOUT), J69.1, J70.1
/CHOUT: C3.1, C5.2, IC1.5 (VIN_1), IC1.6 (VIN_2), IC1.9 (EN), Q1.5 (D), RFB2.2, RFV1.2, RFV2.2, RFV3.2, RP_CHRG1.2, RP_FAULT1.2, U1.1 (VSYS), U1.24 (VSYS)
/CLPROG_2: U1.3 (CLPROG)
/F0: RFG1.2, RFV1.1, U1.14 (F0)
/F1: RFG2.2, RFV2.1, U1.13 (F1)
/F2: RFG3.2, RFV3.1, U1.12 (F2)
/IGATE: Q1.4 (G), Q2.4 (G), U1.15 (IGATE)
/MAG+X: J35.2, J43.9, J47.2
/MAG+Y: J56.2, J57.2, J66.2
/MAG+Z: J37.2, J45.9, J49.2
/MAG-X: J24.9, J34.2, J46.2
/MAG-Y: J39.2, J51.2, J63.14
/MAG-Z: J36.2, J44.9, J48.2
/OVSNS: R4.1, U1.16 (OVSNS)
/PFO_2: U1.20 (PF0#)
/PHT1: J24.3, J34.8, J46.8
/PHT2: J35.8, J43.3, J47.8
/PHT3: J36.8, J44.3, J48.8
/PHT4: J37.8, J45.3, J49.8
/PHT5: J39.8, J51.8, J63.8
/PHT6: J38.8, J50.8, J62.2
/PROG: R2.1, U1.2 (PROG)
/RST_2: U1.11 (RST#)
/SWO: J25.6, J27.4, J28.4, J42.5
/VCC_MAG: J24.8, J34.3, J35.3, J36.3, J37.3, J39.3, J43.8, J44.8, J45.8, J46.3, J47.3, J48.3, J49.3, J51.3, J56.1, J57.1, J63.13, J66.1
/VCC_Umbilical: J27.1, J28.1, J42.8
/VIN: D3.1, F1.2, J71.2, J72.1
/VSUPPLY: F1.1, J54.1, J54.2, J54.3, J54.4, J54.5
ADCS_POWER: J3.3, J6.3, J10.3, J14.8, J17.8, J21.8, J31.3, J58.16, J60.3, J67.16
ADC_PH: J3.5, J6.5, J10.5, J14.6, J17.6, J21.6, J31.5, J58.20, J60.5, J67.20
ADC_PL: J2.9, J5.9, J9.9, J13.2, J20.2, J26.2, J29.9, J30.9, J58.39, J67.39
BATT+: J27.6, J28.6, J40.1, J42.3, J53.1, J64.2, J68.2
BATT-: J1.6, J7.6, J11.6, J15.5, J19.5, J22.5, J27.7, J28.7, J32.6, J39.10, J40.2, J42.2, J51.10, J53.2, J58.19, J59.6, J63.6, J64.1, J67.19, J73.2
BATT_NTC: J4.3, J8.3, J12.3, J16.8, J18.8, J23.8, J33.3, J41.1, J52.1, J58.4, J61.3, J65.3, J67.4
BURNCOMMS: J4.9, J8.9, J12.9, J16.2, J18.2, J23.2, J24.2, J33.9, J34.9, J35.9, J36.9, J37.9, J38.9, J43.2, J44.2, J45.2, J46.9, J47.9, J48.9, J49.9, J50.9, J58.10, J61.9, J62.1, J67.10
CHRG: J3.10, J6.10, J10.10, J14.1, J17.1, J21.1, J31.10, J58.30, J60.10, J67.30, RP_CHRG1.1, U1.8 (CHRG#)
CHRGOFF: J2.2, J5.2, J9.2, J13.9, J20.9, J26.9, J29.2, J30.2, J58.32, J67.32
CLPROG: J2.3, J5.3, J9.3, J13.8, J20.8, J26.8, J29.3, J30.3, J58.33, J67.33
DAC_PL: J2.8, J5.8, J9.8, J13.3, J20.3, J26.3, J29.8, J30.8, J58.38, J67.38
FAULT: J3.9, J6.9, J10.9, J14.2, J17.2, J21.2, J31.9, J58.28, J60.9, J67.28, RP_FAULT1.1, U1.9 (FAULT#)
GND: C1.2, C2.2, C3.2, C4.1, C5.1, D3.2, H1.1, H2.1, H3.1, H4.1, H5.1, H6.1, H7.1, H8.1, H9.1, H10.1, H11.1, H12.1, H13.1, H14.1, H15.1, H16.1, H17.1, H18.1, H19.1, H20.1, H21.1, H22.1, H23.1, H24.1, H25.1, H26.1, H27.1, H28.1, H29.1, H30.1, H31.1, H32.1, H33.1, H34.1, H35.1, H36.1, H37.1, H38.1, H39.1, H40.1, H41.1, H42.1, H43.1, H44.1, H45.1, H46.1, H47.1, H48.1, H49.1, H50.1, H51.1, H52.1, H53.1, H54.1, H55.1, H56.1, H57.1, H58.1, H59.1, H60.1, H61.1, H62.1, H63.1, H64.1, H65.1, H66.1, H67.1, H68.1, H69.1, H70.1, H71.1, H72.1, H73.1, H74.1, H75.1, H76.1, H77.1, H78.1, H79.1, H80.1, H81.1, H82.1, IC1.2 (PGND), IC1.7 (BYPS), IC1.8 (GND), IC1.13 (EP), J1.9, J4.7, J4.10, J7.9, J8.7, J8.10, J11.9, J12.7, J12.10, J15.2, J16.1, J16.4, J18.1, J18.4, J19.2, J22.2, J23.1, J23.4, J24.1, J24.4, J25.3, J25.5, J27.8, J27.MP (MountPin), J28.8, J28.MP (MountPin), J32.9, J33.7, J33.10, J34.7, J34.10, J34.MP (MountPin), J35.7, J35.10, J35.MP (MountPin), J36.7, J36.10, J36.MP (MountPin), J37.7, J37.10, J37.MP (MountPin), J38.2, J38.3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
HEATER_PWR: J4.8, J8.8, J12.8, J16.3, J18.3, J23.3, J33.8, J41.3, J52.3, J58.7, J61.8, J65.1, J67.7
KILLSWITCH+: J1.4, J7.4, J11.4, J15.7, J19.7, J22.7, J32.4, J39.11, J51.11, J58.23, J59.4, J63.5, J67.23
NC: J1.7, J7.7, J11.7, J15.4, J19.4, J22.4, J32.7, J58.17, J59.7, J67.17
NRST: J2.5, J5.5, J9.5, J13.6, J20.6, J25.10, J26.6, J27.5, J28.5, J29.5, J30.5, J39.12, J42.4, J51.12, J58.35, J63.4, J67.35
unnamed: IC1.3 (LX1_1), IC1.4 (LX1_2), L2.1
unnamed: IC1.1 (LX2_1), IC1.12 (LX2_2), L2.2
unnamed: L1.1, U1.21 (SW), U1.22 (SW)
unnamed: J71.1, Q2.5 (D), R4.2, RPF2.1
unnamed: C2.1, J68.1, L1.2, U1.23 (BAT)
unnamed: RFB1.1, RFB2.1, U1.10 (RSTFB), U1.18 (BSTFB)
unnamed: Q1.1 (S), Q1.2 (S), Q1.3 (S), R1.1, U1.7 (CLN)
unnamed: RPF1.1, RPF2.2, U1.19 (PFI)
unnamed: C1.1, Q2.1 (S), Q2.2 (S), Q2.3 (S), R1.2, U1.6 (VIN)
PFO: J1.5, J7.5, J11.5, J15.6, J19.6, J22.6, J32.5, J58.21, J59.5, J67.21
P/L_POWER: J3.6, J6.6, J10.6, J14.5, J17.5, J21.5, J31.6, J58.22, J60.6, J67.22
RST_DRIVERS: J3.4, J6.4, J10.4, J14.7, J17.7, J21.7, J31.4, J58.18, J60.4, J67.18
SCL1: J1.2, J7.2, J11.2, J15.9, J19.9, J22.9, J32.2, J58.27, J59.2, J67.27
SCL3: J2.10, J5.10, J9.10, J13.1, J20.1, J24.5, J26.1, J29.10, J30.10, J34.6, J35.6, J36.6, J37.6, J38.6, J39.6, J43.5, J44.5, J45.5, J46.6, J47.6, J48.6, J49.6, J50.6, J51.6, J58.40, J62.4, J63.10, J67.40
SDA1: J1.1, J7.1, J11.1, J15.10, J19.10, J22.10, J32.1, J58.29, J59.1, J67.29
SDA3: J2.4, J5.4, J9.4, J13.7, J20.7, J24.6, J26.7, J29.4, J30.4, J34.5, J35.5, J36.5, J37.5, J38.5, J39.5, J43.6, J44.6, J45.6, J46.5, J47.5, J48.5, J49.5, J50.5, J51.5, J58.34, J62.5, J63.11, J67.34
SEL_PH0: J3.7, J6.7, J10.7, J14.4, J17.4, J21.4, J31.7, J58.24, J60.7, J67.24
SEL_PH1: J4.6, J8.6, J12.6, J16.5, J18.5, J23.5, J33.6, J58.5, J61.6, J67.5
SEL_PH2: J4.5, J8.5, J12.5, J16.6, J18.6, J23.6, J33.5, J58.6, J61.5, J67.6
SOLAR_X: J2.1, J5.1, J9.1, J13.10, J20.10, J24.10, J26.10, J29.1, J30.1, J34.1, J35.1, J43.10, J46.1, J47.1, J58.31, J67.31
SOLAR_Y: J4.4, J8.4, J12.4, J16.7, J18.7, J23.7, J33.4, J38.1, J39.1, J50.1, J51.1, J58.3, J61.4, J62.9, J63.15, J67.3
SOLAR_Z: J3.1, J6.1, J10.1, J14.10, J17.10, J21.10, J31.1, J36.1, J37.1, J44.10, J45.10, J48.1, J49.1, J58.12, J60.1, J67.12
STM32_PA15: J4.1, J8.1, J12.1, J16.10, J18.10, J23.10, J33.1, J58.2, J61.1, J67.2
STM32_PB0: J3.2, J6.2, J10.2, J14.9, J17.9, J21.9, J31.2, J58.14, J60.2, J67.14
STM32_PB3: J4.2, J8.2, J12.2, J16.9, J18.9, J23.9, J33.2, J39.9, J51.9, J58.1, J61.2, J63.7, J67.1
SWCLK: J2.7, J5.7, J9.7, J13.4, J20.4, J25.4, J26.4, J27.3, J28.3, J29.7, J30.7, J39.13, J42.6, J51.13, J58.37, J63.3, J67.37
SWDIO: J2.6, J5.6, J9.6, J13.5, J20.5, J25.2, J26.5, J27.2, J28.2, J29.6, J30.6, J39.14, J42.7, J51.14, J58.36, J63.2, J67.36
UART_RX: J1.3, J7.3, J11.3, J15.8, J19.8, J22.8, J32.3, J58.25, J59.3, J67.25
UART_TX: J1.8, J7.8, J11.8, J15.3, J19.3, J22.3, J32.8, J58.15, J59.8, J67.15
VCC: D1.1, D2.1, J25.1
VCC_UMBILICAL: D2.2, J3.8, J6.8, J10.8, J14.3, J17.3, J21.3, J31.8, J39.15, J51.15, J58.26, J60.8, J63.1, J67.26, J70.2

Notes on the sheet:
BATTERY
PAYLOAD
TEST POINTS
Logos
ADCS
GND BATTERY
3V3 Selector
CHARGE / DISCHARGE IC
JTAG connector
Mounting holes top
EPS
LATERAL
Vertical
PAYLOAD
BOTTOM
Mounting holes EGSE
Umbilical connector
TOP
Bottom view
OBC + COMMS
Umbilical Power Diode
PAYLOAD ADAPTOR
VOLTAGE REGULATOR
Top view
External supply protection
MAGY
External supply bananas
EGSE - BOARDS
NTC
EPS
Mounting holes magy
BREAKOUT - EGSE
Mounting holes bottom
Mounting Holes bottom
Mounting Holes top
OBC + COMMS
Mounting Holes printed part
MPPT
Mounting holes lateral
Right angle

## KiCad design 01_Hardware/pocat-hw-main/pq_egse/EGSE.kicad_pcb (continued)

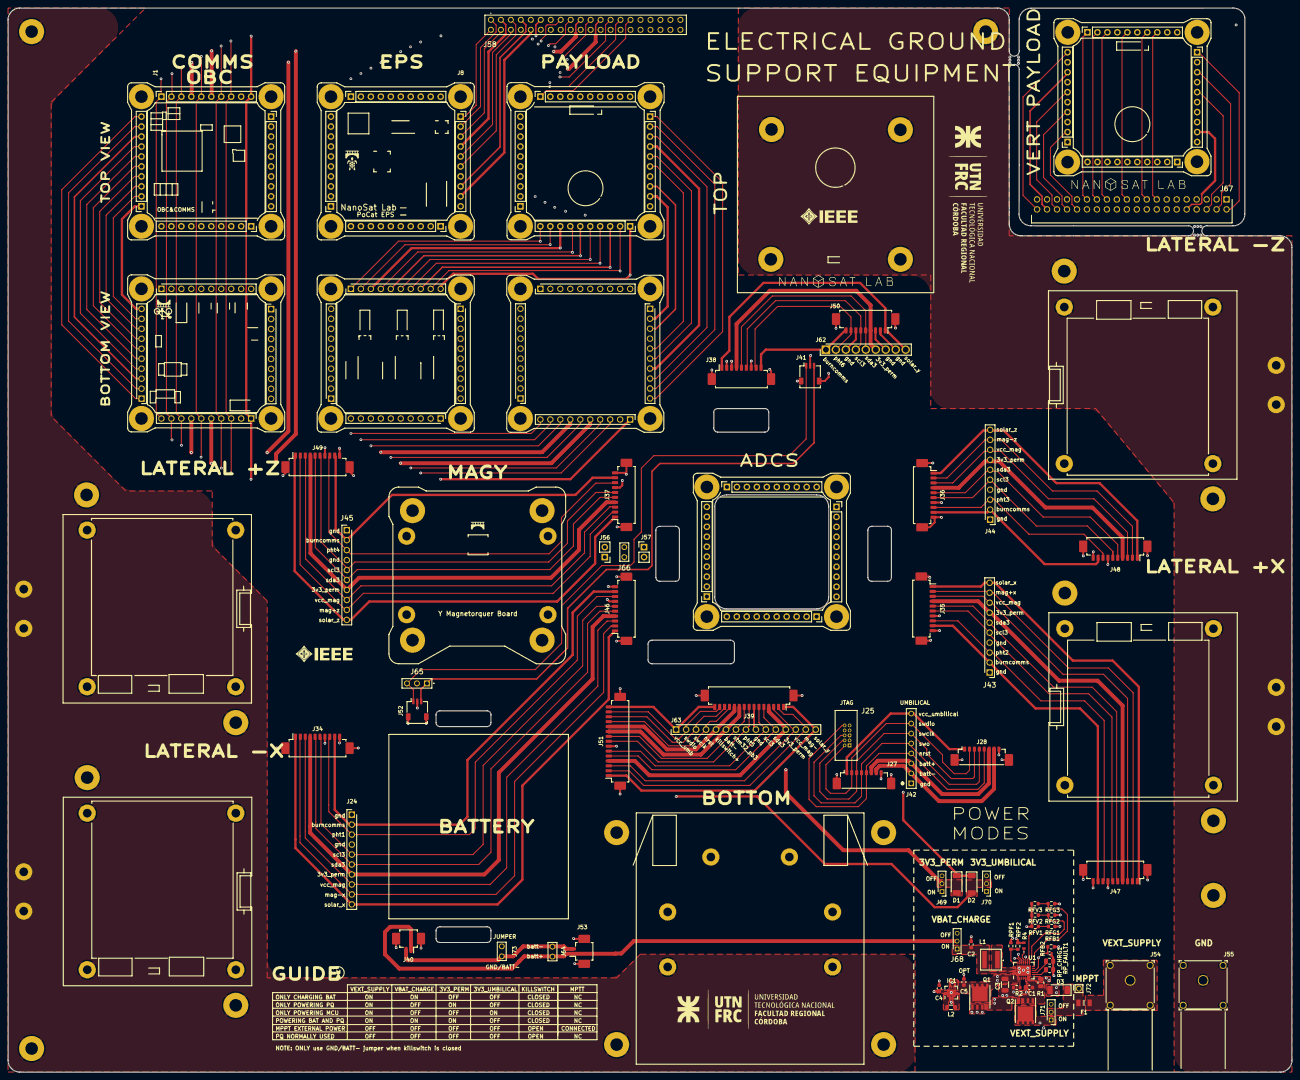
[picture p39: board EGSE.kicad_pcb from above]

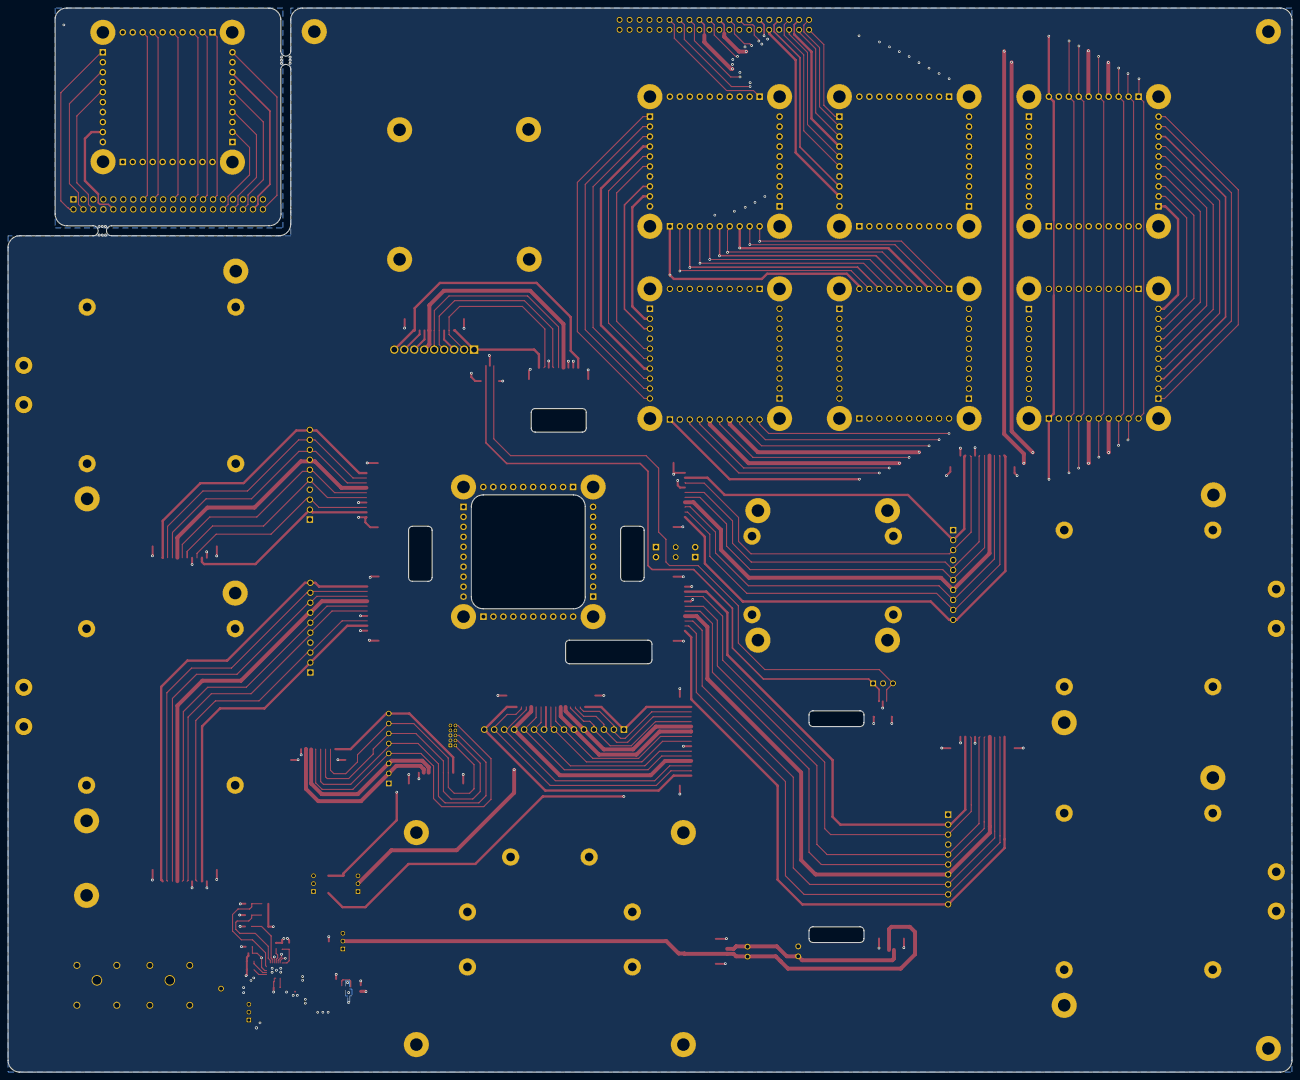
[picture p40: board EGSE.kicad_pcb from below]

Board: 6 copper layers, 327.0 x 271.0 mm, 195 parts (2 on the bottom side), 74 nets.

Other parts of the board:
Annotation1#2: Silkscreen_Annotation; IEEE_logo__Annotation1
Annotation1#3, Annotation1#4: Silkscreen_Annotation; Bridgemaker__Annotation1
Annotation2#2: Silkscreen_Annotation; IEEE_logo__Annotation2
Annotation3#2: Silkscreen_Annotation; NSL_long__Annotation3
mouse-bite-2.54mm-slot, mouse-bite-2.54mm-slot#2: VAL**; mouse-bite-2.54mm-slot__mouse-bite-2.54mm-slot

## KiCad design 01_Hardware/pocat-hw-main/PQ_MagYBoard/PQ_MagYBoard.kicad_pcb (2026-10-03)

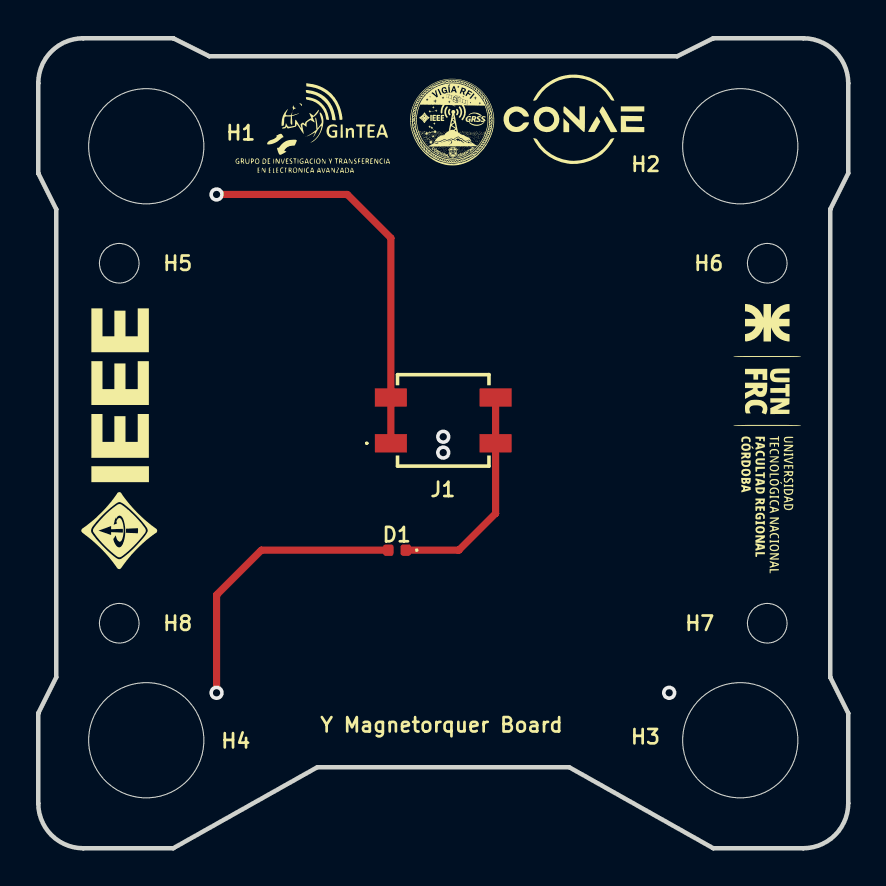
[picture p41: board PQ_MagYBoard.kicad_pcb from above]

Board: 6 copper layers, 45.0 x 45.0 mm, 11 parts (0 on the bottom side), 2 nets.

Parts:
Annotation1: Silkscreen_Annotation; IEEE_logo__Annotation1
D1: LED; D1__96abf5d7
H1: MountingHole; H1__4e36dd2d
H2: MountingHole; H2__04eba765
H3: MountingHole; H3__b5fb1087
H4: MountingHole; H4__a7a81e5c
H5: MountingHole; H5__5195467b
H6: MountingHole; H6__80f6b20b
H7: MountingHole; H7__513e248b
H8: MountingHole; H8__01ccc00b
J1: M20-7810245; J1__1c8c80f3

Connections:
/MAG+Y: D1.1 (K), J1.2, J1.4
/VCC_MAG: D1.2 (A), J1.1, J1.3

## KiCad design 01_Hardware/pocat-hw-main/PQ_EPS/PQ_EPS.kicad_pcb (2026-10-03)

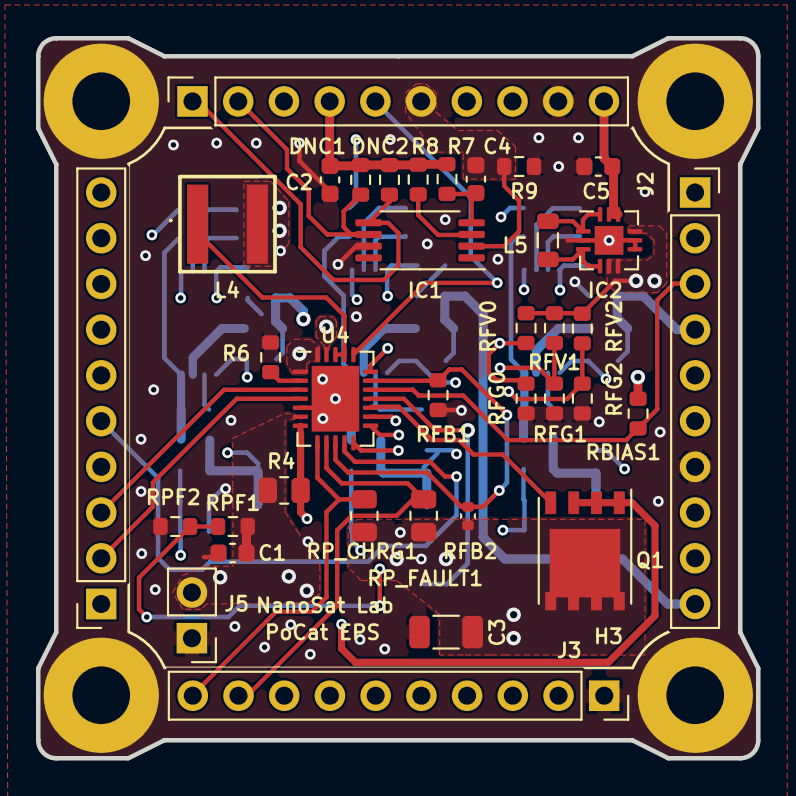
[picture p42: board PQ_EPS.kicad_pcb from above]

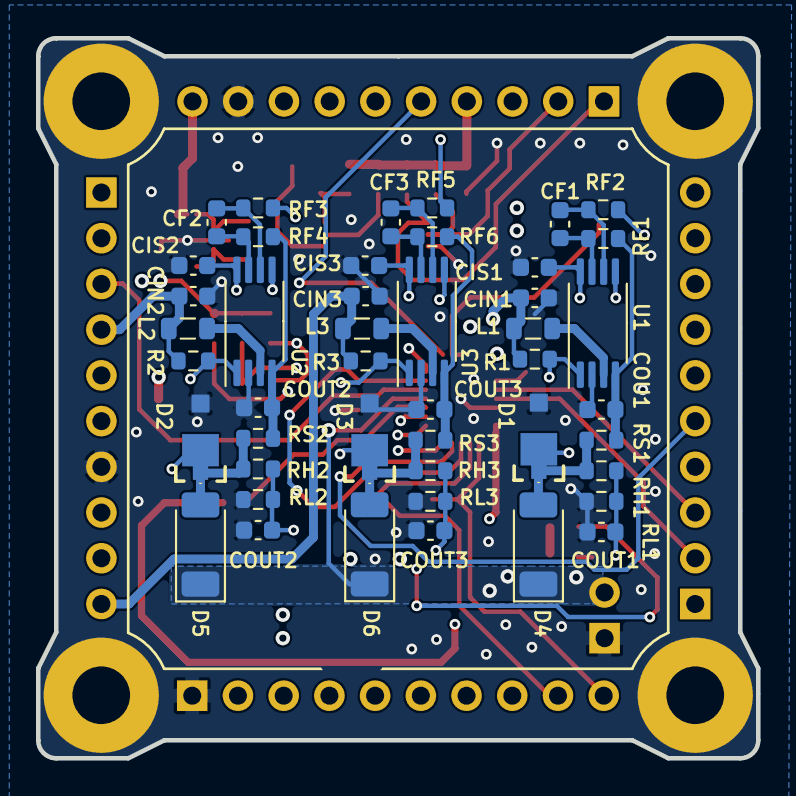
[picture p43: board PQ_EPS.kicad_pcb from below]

Board: 4 copper layers, 40.0 x 40.0 mm, 85 parts (45 on the bottom side), 52 nets.

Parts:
C1: 2.2u; C1__85906104
C2: 10u; C2__3bb3261a
C3: 100u; C3__1b16b82f
C4: 0.1u; C4__8813a4fd
C5: 22u; C5__10c63672
CF1: 1u; CF1__1f269640
CF2: 1u; CF2__bf330c01
CF3: 1u; CF3__dc4340d5
CIN1: 1.5u; CIN1__4d5a425d
CIN2: 1.5u; CIN2__61dff1fe
CIN3: 1.5u; CIN3__7a7f343d
CIS1: 1n; CINSNS1__fe801517
CIS2: 1n; CINSNS2__c8bb742b
CIS3: 1n; CINSNS3__0692e306
COU1: 10u; COUT1__ab158bdd
COUT1: 1n; COUTSNS1__a3c0c3c5
COUT2: 10u; COUT2__652cde38
COUT2#2: 1n; COUTSNS2__7fceb7d9
COUT3: 10u; COUT3__754a9436
COUT3#2: 1n; COUTSNS3__d7212c9c
D1: SMM4F; D1__d6a92ff9
D2: SMM4F; D2__ff0ca32b
D3: SMM4F; D3__e18f0f22
D4: shottky; D4__8296a06b
D5: shottky; D5__9ba6cb21
D6: shottky; D6__c3fa03f0
DNC1: 20k; DNC1__f835551e
DNC2: 20k; DNC2__33baa008
H1: MountingHole_Pad; H1__55b0f0f4
H2: MountingHole_Pad; H2__8e44a857
H3: MountingHole_Pad; H3__b7d146b7
H4: MountingHole_Pad; H4__41eeead0
IC1: DS2782E+; IC1__4bc49ce2
IC2: ISL9120IRTNZ; IC2__20e1d699
J1: CES-110-02-L-S; J1__41ef131c
J2: CES-110-02-L-S; J2__a6eda72d
J3: CES-110-02-L-S; J3__f3199705
J4: CES-110-02-L-S; J4__cbe1d312
J5: J5__02e0e550
L1: 10u; L1__28ad8ce4
L2: 10u; L2__ba5a3009
L3: 10u; L3__2d21b16b
L4: 2.2u; L4__0e1a387a
L5: 1u; L5__3c55d55a
Q1: SIR424DP; Q1__7e14e801
R1: 1k; R1__714a8ecb
R2: 1k; R2__9665c163
R3: 1k; R3__0ad47374
R4: 75m; R4__23007612
R6: 2k; R6__9883130c
R7: 510; R7__5afebccb
R8: 1k; R8__c5a4b0be
R9: 15m; R9__b30fbfff
RBIAS1: 10k; RBIAS1__42875ef3
RF1: 1k; RF1__b4a62e9b
RF2: 1k; RF2__79efa971
RF3: 1k; RF3__bcc6cc11
RF4: 1k; RF4__cdcae543
RF5: 1k; RF5__f4b268ee
RF6: 1k; RF6__ccc287bf
RFB1: 68k; RFB1__c3f0ad02
RFB2: 255k; RFB2__4535851b
RFG0: 1k; RFG0__3a5b81d0
RFG1: 1k; RFG1__e70eb10d
RFG2: 1k; RFG2__d57aa5a1
RFV0: 1k; RFV0__0fa13d2d
RFV1: 1k; RFV1__fbfc8f7b
RFV2: 1k; RFV2__f2fc9b41
RH1: 910k; RH1__fc164062
RH2: 910k; RH2__583a5c2e
RH3: 910k; RH3__ecdadcf0
RL1: 360k; RL1__fa346202
RL2: 360k; RL2__b23261de
RL3: 360k; RL3__61c11c4e
RPF1: 147k; RPF1__76985f45
RPF2: 68k; RPF2__25740c8e
RP_CHRG1: 5k; RP_CHRG1__a22c6ae2
RP_FAULT1: 5k; RP_FAULT1__5c0411cb
RS1: 300m; RS1__0808f33b
RS2: 300m; RS2__556b6153
RS3: 300m; RS3__b8c6c485
U1: SPV1040TTR; U1__eb7258e8
U2: SPV1040TTR; U2__41f13721
U3: SPV1040TTR; U3__48f96149
U4: LTC4040IUFD#PBF; U4__55343438

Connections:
3V3_PERM: C5.2, IC2.10 (FB), IC2.11 (VOUT), J1.10, RBIAS1.2
BATT-: C4.2, IC1.2 (VSS), J1.6, R9.1
BATT_NTC: J2.3, RBIAS1.1, U4.17 (NTC)
CHOUT: C3.1, IC2.5 (VIN_1), IC2.6 (VIN_2), IC2.9 (EN), Q1.5 (D), RFB2.2, RFV0.1, RFV1.1, RFV2.1, RP_CHRG1.1, RP_FAULT1.1, U4.1 (VSYS), U4.24 (VSYS)
CHRG: J3.10, RP_CHRG1.2, U4.8 (CHRG#)
CHRGOFF: J4.2, U4.4 (CHGOFF)
CLPROG: J4.3, U4.3 (CLPROG)
F0: RFG0.1, RFV0.2, U4.14 (F0)
F1: RFG1.1, RFV1.2, U4.13 (F1)
F2: RFG2.1, RFV2.2, U4.12 (F2)
FAULT: J3.9, RP_FAULT1.2, U4.9 (FAULT#)
GND: C1.2, C2.2, C3.2, C5.1, CIN1.1, CIN2.1, CIN3.1, CIS1.1, CIS2.1, CIS3.1, COU1.1, COUT1.1, COUT2.1, COUT2#2.1, COUT3.1, COUT3#2.1, D1.2, D2.2, D3.2, H1.1, H2.1, H3.1, H4.1, IC1.7 (SNS), IC2.2 (PGND), IC2.7 (BYPS), IC2.8 (GND), IC2.13 (EP), J1.9, J2.7, J3.1, J5.1, R6.1, R9.2, RFB1.2, RFG0.2, RFG1.2, RFG2.2, RL1.2, RL2.2, RL3.2, RPF2.1, U1.2 (GND), U2.2 (GND), U3.2 (GND), U4.5 (BSTOFF), U4.25 (EPAD)
KILLSWITCH+: C2.1, DNC1.2, DNC2.2, J1.4, L4.2, R7.2, R8.2, U4.23 (BAT)
NRST: J4.5, U4.11 (RST#)
unnamed: D1.1, D4.2, RF2.2, RH1.1, RS1.2
unnamed: D2.1, D5.2, RF3.2, RH2.1, RS2.2
unnamed: D3.1, D6.2, RF5.2, RH3.1, RS3.2
unnamed: C4.1, IC1.4 (VDD), R7.1
unnamed: IC1.3 (VIN), R8.1
unnamed: IC2.3 (LX1_1), IC2.4 (LX1_2), L5.1
unnamed: IC2.1 (LX2_1), IC2.12 (LX2_2), L5.2
unnamed: L4.1, U4.21 (SW), U4.22 (SW)
unnamed: Q1.4 (G), U4.15 (IGATE)
unnamed: CF1.1, RF2.1, U1.6 (ICTRL-MINUS)
unnamed: CF1.2, RF1.1, U1.7 (ICTRL-PLUS)
unnamed: L1.1, U1.3 (LX)
unnamed: CIS1.2, R1.1, U1.1 (MPP-SET), U1.8 (XSHUT)
unnamed: COUT1.2, RH1.2, RL1.1, U1.5 (VCTRL)
unnamed: COU1.2, RF1.2, RS1.1, U1.4 (VOUT)
unnamed: CF2.1, RF3.1, U2.6 (ICTRL-MINUS)
unnamed: CF2.2, RF4.1, U2.7 (ICTRL-PLUS)
unnamed: L2.2, U2.3 (LX)
unnamed: CIS2.2, R2.1, U2.1 (MPP-SET), U2.8 (XSHUT)
unnamed: COUT2#2.2, RH2.2, RL2.1, U2.5 (VCTRL)
unnamed: COUT2.2, RF4.2, RS2.1, U2.4 (VOUT)
unnamed: CF3.1, RF5.1, U3.6 (ICTRL-MINUS)
unnamed: CF3.2, RF6.1, U3.7 (ICTRL-PLUS)
unnamed: L3.2, U3.3 (LX)
unnamed: CIS3.2, R3.1, U3.1 (MPP-SET), U3.8 (XSHUT)
unnamed: COUT3#2.2, RH3.2, RL3.1, U3.5 (VCTRL)
unnamed: COUT3.2, RF6.2, RS3.1, U3.4 (VOUT)
unnamed: RFB1.1, RFB2.1, U4.10 (RSTFB), U4.18 (BSTFB)
unnamed: Q1.1 (S), Q1.2 (S), Q1.3 (S), R4.2, U4.7 (CLN)
unnamed: RPF1.1, RPF2.2, U4.19 (PFI)
OVSNS: C1.1, D4.1, D5.1, D6.1, J5.2, R4.1, RPF1.2, U4.6 (VIN), U4.16 (OVSNS)
PFO: J1.5, U4.20 (PF0#)
PROG: R6.2, U4.2 (PROG)
SCL1: DNC1.1, IC1.6 (SCL), J1.2
SDA1: DNC2.1, IC1.5 (SDA), J1.1
SOLAR_X: CIN1.2, J4.1, L1.2, R1.2
SOLAR_Y: CIN2.2, J2.4, L2.1, R2.2
SOLAR_Z: CIN3.2, J2.10, L3.1, R3.2

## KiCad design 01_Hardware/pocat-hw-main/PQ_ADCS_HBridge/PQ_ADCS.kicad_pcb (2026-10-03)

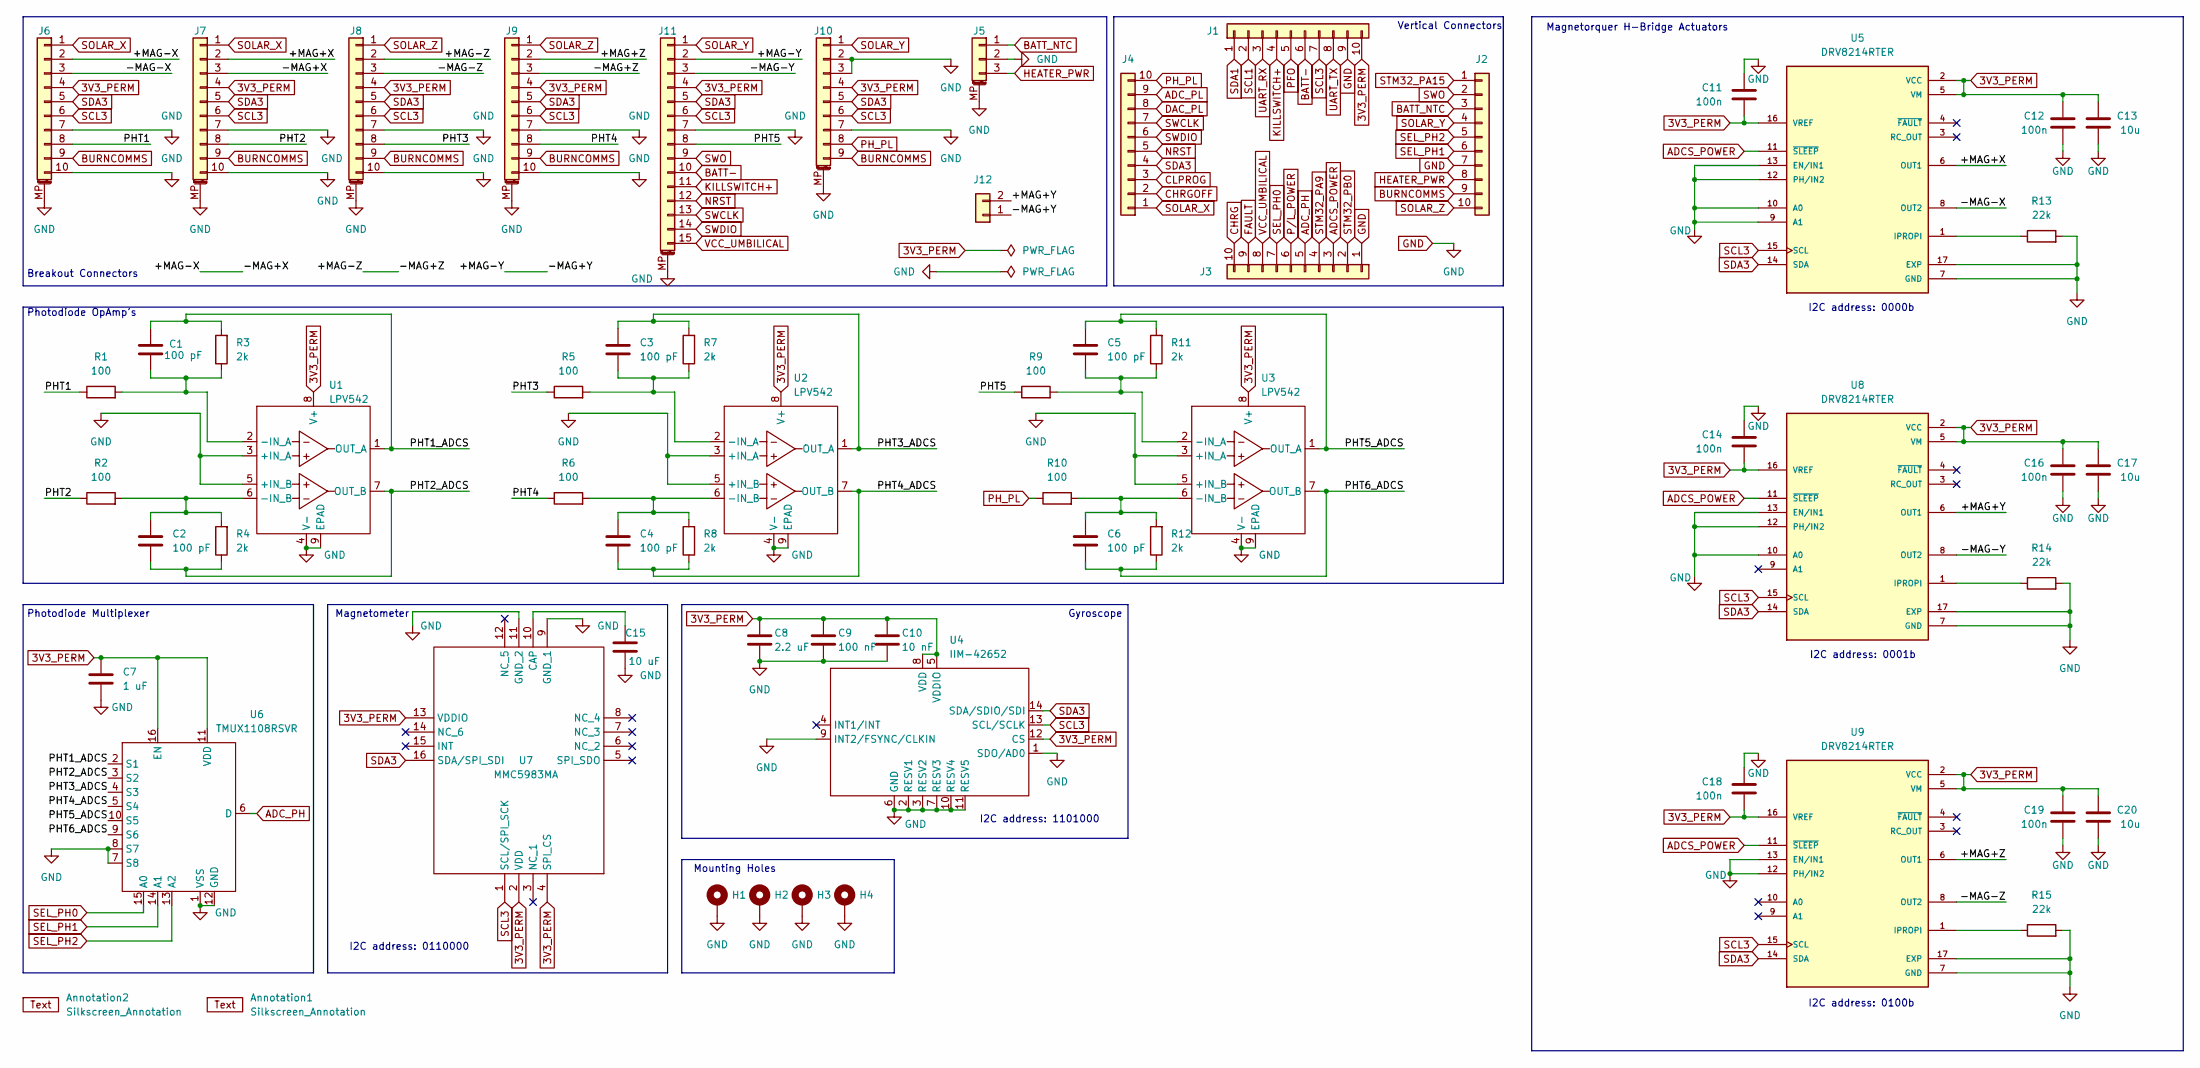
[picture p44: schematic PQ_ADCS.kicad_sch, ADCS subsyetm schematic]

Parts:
Annotation1: Silkscreen_Annotation; Bike
Annotation2: Silkscreen_Annotation; Bridgemaker
C1, C2, C3, C4, C5, C6: 100 pF; C_0603_1608Metric; Manufacturer Part Numbe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 06035C101K4T2A
C7: 1 uF; C_0603_1608Metric; Manufacturer Part Numbe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 GRM188R61A105KA61D
C8: 2.2 uF; C_0603_1608Metric; Manufacturer Part Numbe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 GRM033R60J225ME15D
C9: 100 nF; C_0603_1608Metric; Manufacturer Part Numbe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 GRM188R72A104KA35J
C10: 10 nF; C_0603_1608Metric; Manufacturer Part Numbe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 0201YD103KAT4A
C11, C12, C14, C16, C18, C19: 100n; C_0603_1608Metric
C13, C17, C20: 10u; C_0603_1608Metric
C15: 10 uF; C_0805_2012Metric; Manufacturer Part Numbe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 GRM188R72A104KA35J
H1, H2, H3, H4: MountingHole_Pad; MountingHole_3.2mm_M3_Pad; Manufacturer Part Numbe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 N/A
J1, J2, J3, J4: CES-110-02-L-S; SLW-110-01; Manufacturer Part Numbe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 CES-110-02-L-S
J5: Pico-Clasp_01x03; Picoclasp03; Manufacturer Part Numbe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 203556-0307
J6, J7, J8, J9: Pico-Clasp_01x10; Picoclasp10; Manufacturer Part Numbe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 504449-1007
J10: Pico-Clasp_01x09; Picoclasp09; Manufacturer Part Numbe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 504449-0907
J11: Pico-Clasp_01x15; Picoclasp15; Manufacturer Part Numbe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 504449-1507
J12: CES-102-02-L-S; CES-102-02; Manufacturer Part Numbe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 CES-102-02-L-S
R1, R2, R5, R6, R9, R10: 100; R_0603_1608Metric; Manufacturer Part Numbe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 AC0603FR-13100RL
R3, R4, R7, R8, R11, R12: 2k; R_0603_1608Metric; Manufacturer Part Numbe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 RC0603FR-132KL
R13, R14, R15: 22k; R_0603_1608Metric; Manufacturer Part Numbe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 AC0603FR-13100RL
U1, U2, U3: LPV542; TI_X1SON-8_3x3mm; Manufacturer Part Numbe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 LPV542DNXR
U4: IIM-42652; IIM42652; Manufacturer_Part_Number IIM-42652; Mouser Part Number 410-IIM-42652
U5, U8, U9: DRV8214RTER; IC_DRV8214RTER; PARTREV November 2023
U6: TMUX1108RSVR; UQFN-16_1.8x2.6_Pitch0.4mm; Manufacturer Part Numbe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 TMUX1108RSVR
U7: MMC5983MA; Manufacturer_Part_Number MMC5983MA; Mouser Part Number 438-MMC5983MA

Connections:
3V3_PERM: C7.1, C8.1, C9.1, C10.1, C11.2, C12.1, C13.1, C14.2, C16.1, C17.1, C18.2, C19.1, C20.1, J1.10, J6.4, J7.4, J8.4, J9.4, J10.4, J11.4, U1.8 (V+), U2.8 (V+), U3.8 (V+), U4.5 (VDDIO), U4.8 (VDD), U4.12 (CS), U5.2 (VCC), U5.5 (VM), U5.16 (VREF), U6.11 (VDD), U6.16 (EN), U7.2 (VDD), U7.4 (SPI_CS), U7.13 (VDDIO), U8.2 (VCC), U8.5 (VM), U8.16 (VREF), U9.2 (VCC), U9.5 (VM), U9.16 (VREF)
/+MAG+X: J7.2, U5.6 (OUT1)
/+MAG+Y: J12.2, U8.6 (OUT1)
/+MAG+Z: J9.2, U9.6 (OUT1)
/+MAG-X: J6.2, J7.3
/+MAG-Y: J11.2, J12.1
/+MAG-Z: J8.2, J9.3
/-MAG-X: J6.3, U5.8 (OUT2)
/-MAG-Y: J11.3, U8.8 (OUT2)
/-MAG-Z: J8.3, U9.8 (OUT2)
/PHT1: J6.8, R1.1
/PHT1_ADCS: C1.1, R3.2, U1.1 (OUT_A), U6.2 (S1)
/PHT2: J7.8, R2.1
/PHT2_ADCS: C2.2, R4.1, U1.7 (OUT_B), U6.3 (S2)
/PHT3: J8.8, R5.1
/PHT3_ADCS: C3.1, R7.2, U2.1 (OUT_A), U6.4 (S3)
/PHT4: J9.8, R6.1
/PHT4_ADCS: C4.2, R8.1, U2.7 (OUT_B), U6.5 (S4)
/PHT5: J11.8, R9.1
/PHT5_ADCS: C5.1, R11.2, U3.1 (OUT_A), U6.10 (S5)
/PHT6_ADCS: C6.2, R12.1, U3.7 (OUT_B), U6.9 (S6)
ADCS_POWER: J3.3, U5.11 (~SLEEP), U8.11 (~SLEEP), U9.11 (~SLEEP)
ADC_PH: J3.5, U6.6 (D)
ADC_PL: J4.9
BATT-: J1.6, J11.10
BATT_NTC: J2.3, J5.1
BURNCOMMS: J2.9, J6.9, J7.9, J8.9, J9.9, J10.9
CHRG: J3.10
CHRGOFF: J4.2
CLPROG: J4.3
DAC_PL: J4.8
FAULT: J3.9
GND: C7.2, C8.2, C9.2, C10.2, C11.1, C12.2, C13.2, C14.1, C15.2, C16.2, C17.2, C18.1, C19.2, C20.2, H1.1, H2.1, H3.1, H4.1, J1.9, J2.7, J3.1, J5.2, J5.MP, J6.7, J6.10, J6.MP, J7.7, J7.10, J7.MP, J8.7, J8.10, J8.MP, J9.7, J9.10, J9.MP, J10.2, J10.3, J10.7, J10.MP, J11.7, J11.MP, R13.2, R14.2, R15.2, U1.3 (+IN_A), U1.4 (V-), U1.5 (+IN_B), U1.9 (EPAD), U2.3 (+IN_A), U2.4 (V-), U2.5 (+IN_B), U2.9 (EPAD), U3.3 (+IN_A), U3.4 (V-), U3.5 (+IN_B), U3.9 (EPAD), U4.1 (SDO/AD0), U4.2 (RESV1), U4.3 (RESV2), U4.6 (GND), U4.7 (RESV3), U4.9 (INT2/FSYNC/CLKIN), U4.10 (RESV4), U4.11 (RESV5), U5.7 (GND), U5.9 (A1), U5.10 (A0), U5.12 (PH/IN2), U5.13 (EN/IN1), U5.17 (EXP), U6.1 (VSS), U6.7 (S8), U6.8 (S7), U6.12 (GND), U7.9 (GND_1), U7.11 (GND_2), U8.7 (GND), U8.10 (A0), U8.12 (PH/IN2), U8.13 (EN/IN1), U8.17 (EXP), U9.7 (GND), U9.12 (PH/IN2), U9.13 (EN/IN1), U9.17 (EXP)
HEATER_PWR: J2.8, J5.3
KILLSWITCH+: J1.4, J11.11
NRST: J4.5, J11.12
unnamed: C1.2, R1.2, R3.1, U1.2 (-IN_A)
unnamed: C2.1, R2.2, R4.2, U1.6 (-IN_B)
unnamed: C3.2, R5.2, R7.1, U2.2 (-IN_A)
unnamed: C4.1, R6.2, R8.2, U2.6 (-IN_B)
unnamed: C5.2, R9.2, R11.1, U3.2 (-IN_A)
unnamed: C6.1, R10.2, R12.2, U3.6 (-IN_B)
unnamed: R13.1, U5.1 (IPROPI)
unnamed: C15.1, U7.10 (CAP)
unnamed: R14.1, U8.1 (IPROPI)
unnamed: R15.1, U9.1 (IPROPI)
PFO: J1.5
PH_PL: J4.10, J10.8, R10.1
P/L_POWER: J3.6
SCL1: J1.2
SCL3: J1.7, J6.6, J7.6, J8.6, J9.6, J10.6, J11.6, U4.13 (SCL/SCLK), U5.15 (SCL), U7.1 (SCL/SPI_SCK), U8.15 (SCL), U9.15 (SCL)
SDA1: J1.1
SDA3: J4.4, J6.5, J7.5, J8.5, J9.5, J10.5, J11.5, U4.14 (SDA/SDIO/SDI), U5.14 (SDA), U7.16 (SDA/SPI_SDI), U8.14 (SDA), U9.14 (SDA)
SEL_PH0: J3.7, U6.15 (A0)
SEL_PH1: J2.6, U6.14 (A1)
SEL_PH2: J2.5, U6.13 (A2)
SOLAR_X: J4.1, J6.1, J7.1
SOLAR_Y: J2.4, J10.1, J11.1
SOLAR_Z: J2.10, J8.1, J9.1
STM32_PA9: J3.4
STM32_PA15: J2.1
STM32_PB0: J3.2
SWCLK: J4.7, J11.13
SWDIO: J4.6, J11.14
SWO: J2.2, J11.9
UART_RX: J1.3
UART_TX: J1.8
VCC_UMBILICAL: J3.8, J11.15

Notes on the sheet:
I2C address: 0100b
Mounting Holes
Breakout Connectors
I2C address: 1101000
Photodiode Multiplexer
Gyroscope
I2C address: 0000b
I2C address: 0110000
I2C address: 0001b
Photodiode OpAmp's
Magnetorquer H-Bridge Actuators
Vertical Connectors
Magnetometer



Board: 6 copper layers, 40.0 x 40.0 mm, 61 parts (9 on the bottom side), 53 nets.

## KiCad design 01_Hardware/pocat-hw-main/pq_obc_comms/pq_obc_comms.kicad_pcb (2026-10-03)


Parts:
Annotation1: Silkscreen_Annotation; Annotation1__e7e7156d
C1: 47nF; C1__ca774a57; Manufacturer Part Numbe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 GRM155R71C473KA01J
C2: 47pF; C2__72c49c38; Manufacturer Part Numbe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 GJM1555C1H470JB01J
C3: 100nF; C3__bcfd69c3; Manufacturer Part Numbe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 GRM188R72A104KA35J
C4: 3.3pF; C4__90207b2c; Manufacturer Part Numbe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 600L3R3BT200T
C5: 5.6pF; C5__346fd701; Manufacturer Part Numbe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 600L5R6BTN200T
C6: 39pF; C6__2c3003df; Manufacturer Part Numbe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 GJM1555C1H390FB01D
C7: 2.2pF; C7__ead5be2a; Manufacturer Part Numbe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 600L2R2BT200T
C8: 39pF; C8__3b28bfd6; Manufacturer Part Numbe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 GJM1555C1H390FB01D
C9: 3.3pF; C9__dc49ac9c; Manufacturer Part Numbe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 600L3R3BT200T
C10: 3.3pF; C10__82ed297d; Manufacturer Part Numbe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 600L3R3BT200T
C11: 2.4pF; C11__b2db7fb1; Manufacturer Part Numbe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 600L2R4BW200T
C12: 1.8pF; C12__b2c7e8c6; Manufacturer Part Numbe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 600L1R8BW200T
C13: 1uF; C13__d1b90dea; Manufacturer Part Numbe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 GRM188R61A105KA61D
C14: 1nF; C14__c8ce7f45; Manufacturer Part Numbe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 0603B102K500CT
C15: 1nF; C15__0dffcb91; Manufacturer Part Numbe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 0603B102K500CT
C16: 1uF; C16__58b6b3e1; Manufacturer Part Numbe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 GRM188R61A105KA61D
C17: 470nF; C17__74bd322c; Manufacturer Part Numbe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 GRM188R7YA474KE05D
C18: 100nF; C18__0129d3c2; Manufacturer Part Numbe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 GRM188R72A104KA35J
C31: 4.7uF; C31__e4047c3f; Manufacturer Part Numbe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 GRT188R61E475KE13D
C32: 100nF; C32__096e5967; Manufacturer Part Numbe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 GRM188R72A104KA35J
C33: 100nF; C33__1d37b461; Manufacturer Part Numbe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 GRM188R72A104KA35J
C34: 100nF; C34__f54a60c3; Manufacturer Part Numbe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 GRM188R72A104KA35J
C35: 100nF; C35__eea0baec; Manufacturer Part Numbe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 GRM188R72A104KA35J
C36: 100nF; C36__1330f687; Manufacturer Part Numbe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 GRM188R72A104KA35J
C37: 1uF; C37__f9cb8991; Manufacturer Part Numbe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 GRM188R61A105KA61D
C38: 10pF; C38__fabc3299; Manufacturer Part Numbe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 06035A100GAT2A
C39: 10pF; C39__0234df5a; Manufacturer Part Numbe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 06035A100GAT2A
C40: 20pF; C40__9df9f696; Manufacturer Part Numbe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 GCM1885C2A200JA16D
C41: 20pF; C41__0aea1b69; Manufacturer Part Numbe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 GCM1885C2A200JA16D
C42: 100nF; C42__d2aef4f4; Manufacturer Part Numbe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 GRM188R72A104KA35J
C43: 1uF; C43__5c5681ac; Manufacturer Part Numbe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 GRM188R61A105KA61D
C44: 1uF; C44__a1850039; Manufacturer Part Numbe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 GRM188R61A105KA61D
C45: 1uF; C45__bee54487; Manufacturer Part Numbe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 GRM188R61A105KA61D
D1: RBS1LAM40ATR; D1__334df4c5; Manufacturer Part Numbe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 RBS1LAM40ATR
D2: RBS1LAM40ATR; D2__bd2b3331; Manufacturer Part Numbe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 RBS1LAM40ATR
H1: MountingHole_Pad; H1__a8eef03d
H2: MountingHole_Pad; H2__7afaf494
H3: MountingHole_Pad; H3__f70388f1
H4: MountingHole_Pad; H4__f801a1cd
J1: Conn_01x10; J1__ce21188f; Manufacturer Part Numbe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 CES-110-01-T-S
J2: Conn_01x10; J2__a63bc9cd; Manufacturer Part Numbe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 CES-110-01-T-S
J3: Conn_01x10; J3__57c77339; Manufacturer Part Numbe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 CES-110-01-T-S
J4: Conn_01x10; J4__71042816; Manufacturer Part Numbe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 CES-110-01-T-S
J6: U.FL; J6__95db4f5f; Manufacturer Part Numbe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 U.FL-R-SMT-1(10)
L1: 47nH; L1__f2e2799c; Manufacturer Part Numbe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 0402DC-47NXGRW
L3: 2.5nH; L3__1485d6de; Manufacturer Part Numbe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 LQW15AN2N5B00D
L4: 4.7nH; L4__942f3cf4; Manufacturer Part Numbe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 0402DC-4N7XGRW
L5: 9.1nH; L5__47193893; Manufacturer Part Numbe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 LQW15AN9N1G8ZD
L6: 15nH; L6__ced7a93c; Manufacturer Part Numbe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 LQW15AN15NH00D
L7: 15uH; L7__e08a8504; Manufacturer Part Numbe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 LQM21DN150M70L
R1: 4.7k; R1__fba2bbee; Manufacturer Part Numbe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 CRCW06034K70JNEAC
R2: 4.7k; R2__b8740f1f; Manufacturer Part Numbe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 CRCW06034K70JNEAC
R3: 100R; R3__a8354450; Manufacturer Part Numbe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 RC0603JR-07100RL
R4: 100R; R4__2f764c92; Manufacturer Part Numbe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 RC0603JR-07100RL
R6: 10k; R6__0c1c77f0; Manufacturer Part Numbe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 CRCW040220K0FKEDC
R7: 4.7k; R7__ea538916; Manufacturer Part Numbe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 CRCW06034K70JNEAC
R8: 4.7k; R8__1b786c22; Manufacturer Part Numbe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 CRCW06034K70JNEAC
TP1: CoaxialSwitch_Testpoint; TP1__f9c4e3d2; Manufacturer Part Numbe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 MS-156C3(20)
U1: STM32L476RGTx; U1__2d765caa; Manufacturer Part Numbe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 STM32L476RGT6
U2: SX1262IMLTRT; U2__3c01bf78; Manufacturer Part Numbe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 SX1262IMLTRT
U3: BD2232G-GTR; U3__78de66fb; Manufacturer Part Numbe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 BD2232G-GTR
U4: BD2232G-GTR; U4__5f493963; Manufacturer Part Numbe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 BD2232G-GTR
U5: BGS12PL6E6327XTSA1; U5__751f0fcc; Manufacturer Part Numbe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 BGS12PL6E6327XTSA1
U6: BD2232G-GTR; U6__e26a39a5; Manufacturer Part Numbe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 BD2232G-GTR
U7: BD2232G-GTR; U7__1728c99a; Manufacturer Part Numbe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 BD2232G-GTR
X1: ECS-120-18-33-JEM-TR3; X1__85b5baba; Manufacturer Part Numbe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 ECS-120-18-33-JEM-TR3
X2: FA-128_32.0000MF20X-K5; X2__c5377c9d; Manufacturer Part Numbe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 FA-128 32.0000MF20X-K5
X3: ABS09-32.768KHZ-7-T; X3__40ef0054; Manufacturer Part Numbe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 ABS09-32.768KHZ-7-T

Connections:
3V3_PERM: C3.1, C13.1, C16.1, C18.1, C43.1, C44.1, C45.2, D1.2, J1.10, R4.1, U2.1 (VDD_IN), U2.10 (VBAT), U2.11 (VBAT_IO), U3.1 (IN), U4.1 (IN), U6.1 (IN), U7.1 (IN)
/Boot0: R6.1, U1.60 (BOOT0)
/DIO1: U1.43 (PA10), U2.13 (DIO1)
/DIO2: R3.1, U2.12 (DIO2)
/HEATER_EN: U1.29 (PB10), U6.3 (EN/EN#)
/MISO: U1.35 (PB14), U2.16 (MISO)
/MOSI: U1.36 (PB15), U2.17 (MOSI)
/OSC_IN: C40.1, U1.5 (PH0), X1.1
/OSC_OUT: C41.1, U1.6 (PH1), X1.3
/PoL_ADCS_POWER_EN: U1.23 (PA7), U4.3 (EN/EN#)
/PoL_BURN_EN: U1.30 (PB11), U7.3 (EN/EN#)
/PoL_P/L_EN: U1.37 (PC6), U3.3 (EN/EN#)
/RFswitch_Vcc: C14.1, R4.2, U5.4 (VDD)
/RFswitch_ctrl: C15.1, R3.2, U5.6 (CTRL)
/SCK: U1.34 (PB13), U2.18 (SCK)
/SX1262_BUSY: U1.41 (PA8), U2.14 (BUSY)
/SX1262_NRST: U1.40 (PC9), U2.15 (NRESET)
/SX1262_NSS: U1.33 (PB12), U2.19 (NSS)
/XTA: U2.3 (XTA), X2.3
/XTB: U2.4 (XTB), X2.1
ADCS_POWER: J3.3, U4.5 (OUT)
ADC_PH: J3.5, U1.25 (PC5)
ADC_PL: J4.9, U1.15 (PA1)
BATT-: J1.6
BATT_NTC: J2.3, U1.14 (PA0)
BURNCOMMS: J2.9, U7.5 (OUT)
CHRG: J3.10, U1.28 (PB2)
CHRGOFF: J4.2, U1.17 (PA3)
CLPROG: J4.3, U1.20 (PA4)
DAC_PL: J4.8, U1.21 (PA5)
FAULT: J3.9, U1.24 (PC4)
GND: C1.2, C2.2, C3.2, C5.2, C7.2, C9.2, C10.2, C12.2, C13.2, C14.2, C15.2, C16.2, C17.2, C18.2, C31.2, C32.2, C33.2, C34.2, C35.2, C36.2, C37.2, C38.2, C39.2, C40.2, C41.2, C42.2, C43.2, C44.2, C45.1, H1.1, H2.1, H3.1, H4.1, J1.9, J2.7, J3.1, J6.2 (Ext), R6.2, TP1.G, U1.12 (VSSA), U1.18 (VSS), U1.31 (VSS), U1.47 (VSS), U1.63 (VSS), U2.2 (GND), U2.5 (GND), U2.8 (GND), U2.20 (GND), U2.25 (GND), U3.2 (GND), U4.2 (GND), U5.2 (GND), U6.2 (GND), U7.2 (GND), X1.2, X1.4, X2.2, X2.4
HEATER_PWR: J2.8, U6.5 (OUT)
KILLSWITCH+: J1.4
NRST: C42.1, J4.5, U1.7 (NRST)
unnamed: C4.1, L1.2, L3.1, TP1.O
unnamed: C4.2, C5.1, C6.1, L3.2
unnamed: C6.2, L4.1
unnamed: C8.2, C9.1, L5.1
unnamed: C10.1, J6.1 (In), L5.2
unnamed: L7.2, U2.9 (DCC_SW)
unnamed: C11.1, L6.1, U2.22 (RFI_N)
unnamed: C12.1, L6.2, U2.21 (RFI_P)
unnamed: TP1.I, U2.23 (RFO)
unnamed: C17.1, L7.1, U2.7 (VREG)
unnamed: C1.1, C2.1, L1.1, U2.24 (VR_PA)
unnamed: C11.2, U5.3 (RF1)
unnamed: C7.1, L4.2, U5.1 (RF2)
unnamed: C8.1, U5.5 (RFIN)
OSC32_IN: C38.1, U1.3 (PC14), X3.1
OSC32_OUT: C39.1, U1.4 (PC15), X3.2
PFO: J1.5, U1.57 (PB5)
PH_PL: J4.10
SCL1: J1.2, R7.2, U1.58 (PB6)
SCL3: J1.7, R1.2, U1.8 (PC0)
SDA1: J1.1, R8.2, U1.59 (PB7)
SDA3: J4.4, R2.2, U1.9 (PC1)
SEL_PH0: J3.7, U1.10 (PC2)
SEL_PH1: J2.6, U1.44 (PA11)
SEL_PH2: J2.5, U1.45 (PA12)
SOLAR_X: J4.1
SOLAR_Y: J2.4
SOLAR_Z: J2.10
STM32_PA9: J3.4, U1.42 (PA9)
STM32_PA15: J2.1, U1.50 (PA15)
STM32_PB0: J3.2, U1.26 (PB0)
SWCLK: J4.7, U1.49 (PA14)
SWDIO: J4.6, U1.46 (PA13)
SWO: J2.2, U1.55 (PB3)
UART_RX: J1.3, U1.52 (PC11)
UART_TX: J1.8, U1.51 (PC10)
VCC: C31.1, C32.1, C33.1, C34.1, C35.1, C36.1, C37.1, D1.1, D2.1, R1.1, R2.1, R7.1, R8.1, U1.1 (VBAT), U1.13 (VDDA), U1.19 (VDD), U1.32 (VDD), U1.48 (VDDUSB), U1.64 (VDD)
VCC_UMBILICAL: D2.2, J3.8

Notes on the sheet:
VDD2
MCU Decoupling capacitors
LoRa RF chain
SX1262 Clock Reference
Umbilical Power Diode
VDD1
Low speed external
Vertical Connectors
MCU
VDD3
VDDA
High speed external
Mounting Holes
VDD4
PoL

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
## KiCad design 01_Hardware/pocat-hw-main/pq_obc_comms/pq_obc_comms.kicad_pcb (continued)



Board: 4 copper layers, 40.0 x 40.0 mm, 68 parts (17 on the bottom side), 68 nets.

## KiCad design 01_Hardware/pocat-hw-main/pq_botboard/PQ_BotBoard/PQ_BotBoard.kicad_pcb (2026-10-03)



Board: 6 copper layers, 64.0 x 52.0 mm, 32 parts (9 on the bottom side), 23 nets.

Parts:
Annotation2: IEEE; IEEE_logo
Annotation7: pocat lektron; pocat-lektron
Annotation8: NSL_long; NSL-small
Annotation9: NSL_hex; NSL_hexagon
C1: 1 uF; C_0603_1608Metric
C2, C3: 10uF; C_0603_1608Metric
D1: SLCD-61N8
D2: LED; LED_0402_1005Metric
D3: RBS1LAM40ATR_Schottky
GA0, GA1, GA2: 0R; R_0805_2012Metric
H1, H2, H3, H4, H5, H6: MountingHole_Pad; MountingHole_2.2mm_M2_Pad
IC1: TCN75AVOA713; TCN75AVOA
J1: 53261-1471; Molex_PicoBlade_53261-1571_1x15-1MP_P1.25mm_Horizontal
J2: Conn_01x08_MountingPin; Molex_PicoBlade_53398-0871_1x08-1MP_P1.25mm_Vertical
J5: Conn_01x03_MountingPin; Molex_PicoBlade_53261-0371_1x03-1MP_P1.25mm_Horizontal
KS1: D2F-01L-A1; D2FLA1
KS2: D2F-01L-A; D2FLA
R1: 340k; R_0603_1608Metric
R2: 50k; R_0603_1608Metric
SC2: Lighttricity_S3040_CIC
U1: TPS7A7002DDAR; TI_SO-PowerPAD-8
VA0, VA1, VA2: 0R; R_0805_2012Metric

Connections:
/BATT+: C3.1, J5.1, KS1.1 (COM), R1.1, U1.6 (OUT)
/BATT-: C2.2, C3.2, J1.10, J2.7, J5.3, R2.1, U1.8 (GND), U1.9 (EP)
/CHARGE+: D3.2, J2.6
/KILLSWITCH+: J1.11, KS2.3 (NC)
/MAG-Y: D2.1 (K), J1.2
/NRST: J1.12, J2.5
/PH+: D1.1, J1.8
/SCL: IC1.2 (SCL), J1.6
/SDA: IC1.1 (SDA), J1.5
/SOLAR_Y: J1.1, SC2.3
/SWCLK: J1.13, J2.3
/SWDIO: J1.14, J2.2
/SWO: J1.9, J2.4
/VCC: C1.1, IC1.8 (VDD), J1.4, VA0.2, VA1.2, VA2.2
/VCC_MAG: D2.2 (A), J1.3
/VCC_Umbilical: J1.15, J2.1
GND: C1.2, D1.2, GA0.2, GA1.2, GA2.2, H1.1, H2.1, H3.1, H4.1, H5.1, H6.1, IC1.3 (ALERT), IC1.4 (GND), J1.7, J1.MP (MountPin), J2.8, J2.MP (MountPin), J5.MP (MountPin), SC2.1
unnamed: GA0.1, IC1.7 (A0), VA0.1
unnamed: GA1.1, IC1.6 (A1), VA1.1
unnamed: GA2.1, IC1.5 (A2), VA2.1
unnamed: KS1.3 (NC), KS2.1 (COM)
unnamed: C2.1, D3.1, U1.2 (EN), U1.3 (IN)
unnamed: R1.2, R2.2, U1.7 (FB)

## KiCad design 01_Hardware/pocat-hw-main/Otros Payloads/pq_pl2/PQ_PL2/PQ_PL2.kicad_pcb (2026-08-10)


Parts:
Annotation1: Silkscreen_Annotation; Bridgemaker; Manufacturer Part Numbe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 N/A
Annotation2: Silkscreen_Annotation; GRSS; Manufacturer Part Numbe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 N/A
Annotation3: Silkscreen_Annotation; NSL_long; Manufacturer Part Numbe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 N/A
Annotation4: Silkscreen_Annotation; IEEE_logo; Manufacturer Part Numbe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 N/A
Annotation5: Silkscreen_Annotation; UPC_positiu; Manufacturer Part Numbe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 N/A
C1, C2, C3, C4, C32: 1nF; C_0603_1608Metric; Manufacturer Part Numbe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 885382206005
C5, C6, C9, C10, C14, C34: 47nF; C_0603_1608Metric; Manufacturer Part Numbe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 CGA3E3X7S2A473K080AE
C7, C8: 47nF; C_0402_1005Metric; Manufacturer Part Numbe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 MAASU105SB7473KFCA01
C11: 2.2pF; C_0603_1608Metric; Manufacturer Part Numbe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 06031U2R2CAT2A
C12: 270pF; C_0603_1608Metric; Manufacturer Part Numbe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 06031A271FAT2A
C13: 22pF; C_0603_1608Metric; Manufacturer Part Numbe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 CBR06C220J5GACAUTO
C15, C16: 1.2nF; C_0603_1608Metric; Manufacturer Part Numbe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 C0603C122F1GACTU
C17, C23: 300pF; C_0402_1005Metric; Manufacturer Part Numbe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 GRT1555C1H301FA02D
C18, C19, C21, C22: 1.3pF; C_0402_1005Metric; Manufacturer Part Numbe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 CBR04C139A5GAC
C20: 500pF; C_0402_1005Metric; Manufacturer Part Numbe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 0402ZC501KAT2A
C24, C25: 12 pF; C_0402_1005Metric; Manufacturer Part Numbe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 CBR04C120F2GAC
C26, C27: 10nF; C_0402_1005Metric; Manufacturer Part Numbe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 GRM1555C1E103GE01D
C28: 27pF; C_0603_1608Metric; Manufacturer Part Numbe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 CBR04C270F2GAC
C29: 33nF; C_0603_1608Metric; Manufacturer Part Numbe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 0402YC333JAT2A
C30, C33: 1uF; C_0603_1608Metric; Manufacturer Part Numbe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 MAASA105CD7105KFCA01
C31: 4.7uF; C_0603_1608Metric; Manufacturer Part Numbe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 C1005X5R1A475K050BC
D1: SLCD-61N8; Manufacturer Part Numbe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 SLCD-61N8
FL1: BFCG162W; GE0805C-3; Manufacturer Part Numbe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 BFCG-162W+
H1, H2, H3, H4: MountingHole_Pad; MountingHole_3.2mm_M3_Pad; Manufacturer Part Numbe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 N/A
J1, J2, J3, J4: BBL-110-Y-X; Manufacturer Part Numbe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 BBL-110-Y-X
J5, J8: U.FL-R-SMT; U.FL-R-SMT-1(10); Manufacturer Part Numbe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 U.FL-R-SMT-1(10); JLCPCB PART CLASS Extended Part
J6, J7: MS-156C3; CoaxialSwitch_Hirose_MS-156C3_Horizontal; Manufacturer Part Numbe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 MS-156C3
L1: 100nH; L_0603_1608Metric; Manufacturer Part Numbe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 7447860210G
L2, L8: 16.4nH; L_0402_1005Metric; Manufacturer Part Numbe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 LQG15WZ16NG02D
L3, L4, L6, L7: 3.9nH; L_0402_1005Metric; Manufacturer Part Numbe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 LQW15AN3N9G80D
L5: 10.2nH; L_0402_1005Metric; Manufacturer Part Numbe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 LQG15WZ10NG02D
L9: 680 nH; L_0402_1005Metric; Manufacturer Part Numbe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 MLF1005GR68KT000
L10: 4.7uH; L_0603_1608Metric; Manufacturer Part Numbe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 MLF1608A3R3JTD25
R1: 87.5; R_0603_1608Metric; Manufacturer Part Numbe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 ERA-3AEB86R6V
R2, R3: 75; R_0603_1608Metric; Manufacturer Part Numbe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 TNPU060375R0BZEN0
R4: 120k; R_0603_1608Metric; Manufacturer Part Numbe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 TNPW0603120KBYEN
R5: 15k; R_0603_1608Metric; Manufacturer Part Numbe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 RP0603BRD0715KL
R6, R7: 33K; R_0603_1608Metric; Manufacturer Part Numbe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 RP0603BRD0733KL
R10: 360k; R_0603_1608Metric; Manufacturer Part Numbe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 RP0603BRD072KL
R11: 120k; R_0603_1608Metric; Manufacturer Part Numbe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 RP0603BRD072KL
U1: LEE2-6+; WSON-6-1EP_2x2mm_P0.65mm_EP1x1.6mm; Manufacturer Part Numbe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 LEE2-6+
U2: MAX2121; QFN50P500X500X80-29N; Manufacturer Part Numbe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 MAX2121
U3: LT5537; SON50P200X300X80-9N-D; Manufacturer Part Numbe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 LT5537
U4: LT3048; SON45P200X200X80-9N; Manufacturer Part Numbe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 LT3048
Y1: ECS-TXO-2016MV; ECSTXO201633320TR; Manufacturer Part Numbe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 ECS-TXO-2016MV

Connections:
3V3_PERM: J1.10
5V: C33.2, R1.1, R10.2, U4.6 (LDOUT)
A+: C18.1, L3.2
A-: C19.1, L4.2
ADCS_POWER: J3.3
ADC_PH: J3.5
ADC_PL: C28.1, J4.9, R7.2
B+: C20.2, C21.2, L3.1, L5.1
B-: C20.1, C22.2, L4.1, L5.2
BATT-: J1.6
BATT_NTC: J2.3
BURNCOMMS: J2.9
C+: C21.1, L6.2
C-: C22.1, L7.2
CHGOFF: J4.2
CHRG: J3.10
CLPROG: J4.3
D+: C24.1, C26.2, L9.2
D-: C25.1, C27.2, L9.1
DAC_PL: J4.8, U2.5 (GC1)
E+: C26.1, U3.2 (IN+)
E-: C27.1, U3.3 (IN-)
FAULT: J3.9
GND: C4.2, C11.2, C13.2, C14.2, C28.2, C30.2, C31.1, C32.1, C33.1, C34.1, D1.2, FL1.2 (GND), FL1.4 (GND), H1.1, H2.1, H3.1, H4.1, J1.9, J2.7, J2.10, J5.2, J6.G, J7.G, J8.2, R2.2, R3.2, R5.2, R6.1, R11.1, U1.1 (NC), U1.3 (NC), U1.4 (NC), U1.6 (NC), U1.7 (GND), U2.3 (GND), U2.10 (GNDTUNE), U2.11 (GNDSYN), U2.28 (ADDR), U2.29 (EP), U3.7 (VEE), U3.9 (EPAD), U4.3 (GND1), U4.9 (GND2), Y1.2 (GND); also elsewhere on the board
HEATER_PWR: J2.8
IF+: C8.1, C17.2, C18.2, L2.1
IF-: C7.1, C17.1, C19.2, L2.2
IO+: C8.2, U2.19 (IOUT+)
IO-: C7.2, U2.20 (IOUT-)
KILLSWITCH+: J1.4
NRST: J4.5
unnamed: C1.1, J5.1
unnamed: C2.2, J6.I
unnamed: C9.1, R2.1
unnamed: C10.1, R3.1
unnamed: C12.2, R5.1
unnamed: C16.2, J8.1
unnamed: FL1.1 (IN), J6.O
unnamed: C3.1, FL1.3 (Out)
unnamed: L1.1, R1.2
unnamed: C1.2, U1.2 (In)
unnamed: C2.1, L1.2, U1.5 (Out&DCin)
unnamed: C14.1, U2.8 (BYPVCO)
unnamed: C12.1, C13.1, R4.2, U2.12 (CPOUT)
unnamed: C6.1, U2.21 (IDC+)
unnamed: C6.2, U2.22 (IDC-)
unnamed: C5.1, U2.23 (QDC+)
unnamed: C5.2, U2.24 (QDC-)
unnamed: C10.2, U2.17 (QOUT+)
unnamed: C9.2, U2.18 (QOUT-)
unnamed: C16.1, U2.15 (REFOUT)
unnamed: J7.O, U2.4 (RFIN)
unnamed: C11.1, R4.1, U2.9 (TUNEVCO)
unnamed: C15.1, U2.14 (XTAL)
unnamed: C29.2, U3.4 (CAP+)
unnamed: C29.1, U3.5 (CAP-)
unnamed: R6.2, R7.1, U3.8 (OUT)
unnamed: C31.2, U4.8 (BSTOUT)
unnamed: C32.2, U4.4 (BYP)
unnamed: R10.1, R11.2, U4.5 (FB)
unnamed: L10.2, U4.1 (SW)
unnamed: C15.2, Y1.3 (Out)
PFO: J1.5
PH_PL: D1.1, J4.10
P/L_POWER: C4.1, C30.1, C34.2, J3.6, L10.1, U2.1 (VCC_RF1), U2.2 (VCC_RF2), U2.6 (VCC_LO), U2.7 (VCC_VCO), U2.13 (VCC_SYN), U2.16 (VCC_DIG), U2.25 (VCC_BB), U3.1 (ENBL), U3.6 (VCC), U4.2 (VIN), U4.7 (EN), Y1.1 (Tri), Y1.4 (VDD); also elsewhere on the board
RF: C3.2, J7.I
RSSI+: C23.2, C25.2, L6.1, L8.1
RSSI-: C23.1, C24.2, L7.1, L8.2
RST_DRIVERS: J3.4
SCL1: J1.2, U2.27 (SCL)
SCL3: J1.7
SDA1: J1.1, U2.26 (SDA)
SDA3: J4.4
SEL_PH0: J3.7
SEL_PH1: J2.6
SEL_PH2: J2.5
SOLAR_X: J4.1
SOLAR_Y: J2.4
SOLAR_Z: J3.1
STM32_PA15: J2.1
STM32_PB0: J3.2; also elsewhere on the board
SWCLK: J4.7
SWDIO: J4.6
SWO: J2.2
UART_RX: J1.3
UART_TX: J1.8
VCC_UMBILICAL: J3.8

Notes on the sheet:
add stowing &deployment mechanism
VERTICAL CONNECTORS
MOUNTING HOLES
IF CHAIN
5 V BOOSTER
RF CHAIN
TUNER
RSSI
ANNOTATIONS
PHOTODIODE



Board: 4 copper layers, 40.0 x 40.0 mm, 81 parts (67 on the bottom side), 59 nets.

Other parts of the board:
C35: 100 pF; C_0603_1608Metric
R8: 100; R_0603_1608Metric
R9: 2k; R_0603_1608Metric
U5: TL071; TSOT-23-5

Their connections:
GND: U5.3 (+), U5.5 (V+); also elsewhere on the board
unnamed: C35.2, R8.2, R9.1
unnamed: R8.1, U5.4 (-)
P/L_POWER: U5.2 (V-); also elsewhere on the board
STM32_PB0: C35.1, R9.2, U5.1; also elsewhere on the board

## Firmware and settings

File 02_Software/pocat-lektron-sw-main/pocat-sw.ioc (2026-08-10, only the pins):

Mcu.UserName=STM32L476RGTx
PA0.Signal=ADCx_IN5
PA1.Signal=ADCx_IN6
PA10.Signal=GPXTI10
PA11.Signal=GPIO_Output
PA12.Signal=GPIO_Output
PA3.Signal=GPIO_Output
PA4.Signal=COMP_DAC11_group
PA5.Signal=COMP_DAC12_group
PA6.Signal=ADCx_IN11
PA7.Signal=GPIO_Input
PA8.Signal=GPIO_Input
PA9.Signal=GPIO_Output
PB0.Signal=GPIO_Output
PB1.Signal=ADCx_IN16
PB10.Signal=GPIO_Output
PB11.Signal=GPIO_Output
PB12.Signal=SPI2_NSS
PB13.Signal=SPI2_SCK
PB14.Signal=SPI2_MISO
PB15.Signal=SPI2_MOSI
PB5.Signal=GPIO_Input
PB6.Signal=I2C1_SCL
PB7.Signal=I2C1_SDA
PC0.Signal=GPIO_Output
PC10.Signal=UART4_TX
PC11.Signal=UART4_RX
PC13.GPIO_Label=B1 [Blue PushButton]
PC13.Signal=GPXTI13
PC2.Signal=GPIO_Output
PC3.Signal=GPIO_Output
PC4.Signal=GPIO_Input
PC5.Signal=ADCx_IN14
PC9.Signal=GPIO_Output

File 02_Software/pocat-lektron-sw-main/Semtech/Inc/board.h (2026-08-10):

/*
  ______                              _
 / _____)             _              | |
( (____  _____ ____ _| |_ _____  ____| |__
 \____ \| ___ |    (_   _) ___ |/ ___)  _ \
 _____) ) ____| | | || |_| ____( (___| | | |
(______/|_____)_|_|_| \__)_____)\____)_| |_|
    (C)2013 Semtech

Description: Target board general functions implementation

License: Revised BSD License, see LICENSE.TXT file include in the project

Maintainer: Miguel Luis and Gregory Cristian
*/
#ifndef __BOARD_H__
#define __BOARD_H__

#include <stdbool.h>
#include <stdlib.h>
#include <stdio.h>
#include <string.h>
#include <stdint.h>
#include "stm32l4xx.h"
#include "stm32l4xx_hal.h"
#include "stm32l4xx_hal_conf.h"
#include "utilities.h"
#include "timer.h"
#include "delay.h"
#include "gpio.h"
#include "spi.h"
#include "radio.h"
#include "sx126x.h"
#include "sx126x-board.h"
#include "rtc-board.h"


#include "stm32l4xx_it.h"
/*!
 * Generic definition
 */
#ifndef SUCCESS
#define SUCCESS                                     1
#endif

#ifndef FAIL
#define FAIL                                        0
#endif

/*!
 * Board MCU pins definitions
 */
#define RADIO_RESET                                 PC_9//PA_0	//Check this lines => IS NRESET!!!

#define RADIO_MOSI                                  PB_15//PA_7
#define RADIO_MISO                                  PB_14//PA_6
#define RADIO_SCLK                                  PB_13//PA_5
#define RADIO_NSS                                   PB_12//PA_8

#define RADIO_BUSY                                  PA_8//PB_3
#define RADIO_DIO_1                                 PA_10//PB_4
#define RADIO_DIO_2									NC //DIO2 IS NOT CONNECTED

#define ANT_SWITCH_POWER                            PC_8//PA_9	//Check this lines

#define OSC_LSE_IN                                  PC_14
#define OSC_LSE_OUT                                 PC_15

#define OSC_HSE_IN                                  PH_0
#define OSC_HSE_OUT                                 PH_1

#define SWCLK                                       PA_14
#define SWDAT                                       PA_13

#define I2C_SCL                                     PB_6//PB_8
#define I2C_SDA                                     PB_7//PB_9

#define UART_TX                                     PC_10//PA_2
#define UART_RX                                     PC_11//PA_3

#define LED_1                                       PC_7//PC_1	//Check this lines
#define LED_2                                       PC_6//PC_0	//Check this lines

#define FR                                          PA_12//PA_1	//Check this lines NOT USED
#define OPT                                         PA_11//PB_0	//Check this lines NOT USED
#define DEVICE_SEL                                  PB_9//PA_4	//Check this lines


/*!
 * Possible power sources
 */
enum BoardPowerSources
{
    USB_POWER = 0,
    BATTERY_POWER,
};

/*!
 * \brief Disable interrupts
 *
 * \remark IRQ nesting is managed
 */
void BoardDisableIrq( void );

/*!
 * \brief Enable interrupts
 *
 * \remark IRQ nesting is managed
 */
void BoardEnableIrq( void );

/*!
 * \brief Initializes the target board peripherals.
 */
void BoardInitMcu( void );

/*!
 * \brief Initializes the boards peripherals.
 */
void BoardInitPeriph( void );

/*!
 * \brief De-initializes the target board peripherals to decrease power
 *        consumption.
 */
void BoardDeInitMcu( void );

/*!
 * \brief Measure the Battery voltage
 *
 * \retval value  battery voltage in volts
 */
uint32_t BoardGetBatteryVoltage( void );

/*!
 * \brief Get the current battery level
 *
 * \retval value  battery level [  0: USB,
 *                                 1: Min level,
 *                                 x: level
 *                               254: fully charged,
 *                               255: Error]
 */
uint8_t BoardGetBatteryLevel( void );

/*!
 * Returns a pseudo random seed generated using the MCU Unique ID
 *
 * \retval seed Generated pseudo random seed
 */
uint32_t BoardGetRandomSeed( void );

/*!
 * \brief Gets the board 64 bits unique ID
 *
 * \param [IN] id Pointer to an array that will contain the Unique ID
 */
void BoardGetUniqueId( uint8_t *id );

/*!
 * \brief Get the board power source
 *
 * \retval value  power source [0: USB_POWER, 1: BATTERY_POWER]
 */
uint8_t GetBoardPowerSource( void );

#endif // __BOARD_H__

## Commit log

2026-08-10 Agrego archivos base del proyecto
    [Antenna_Tape.SLDPRT, Antenna_Tape_Sheet.SLDPRT, BN 20146 3233654 hexalobular socket head cap screw M2x5.SLDPRT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]
2026-08-12 Add files via upload
    Este documento presenta una estructura de organización para la distribución de tareas mecánicas
2026-08-13 WBS de electrónica
2026-08-14 Agrego al WBS sobre la placa EGSE
2026-08-14 Agrego al WBS PDF sobre la placa EGSE y cambio nombre
2026-08-17 Add files via upload
    Documento instructivo sobre plataforma de organización de tareas
2026-08-18 Esquema de distribución de tareas Mecánicas
2026-10-03 Pcbs actualizados corregidos (son definitivos para mandarlos a fabricar con sus respectivos Gebers en una carpeta separada)
    [DRV8214RTER.step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]
2026-10-03 carpeta vieja
    [PQ_MagYBoard.kicad_pcb, PQ_MagYBoard.kicad_sch, PQ_MagYBoard.step]
2026-10-03 README.md actualizado de la parte de Hardware
2026-10-05 BOM final
    [BOM_final_final.xlsx]

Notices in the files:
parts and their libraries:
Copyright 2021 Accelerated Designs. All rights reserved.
